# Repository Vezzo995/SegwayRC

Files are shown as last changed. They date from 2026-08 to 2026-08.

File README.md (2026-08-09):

# SegwayRC

Firmware for **SegwayRC**, a two-wheel self-balancing RC robot.
Arduino Nano · MPU-6050 · 2× NEMA 17 driven by TB6600 drivers.

📦 **3D model, bill of materials and assembly instructions:** [SegwayRC on MakerWorld](https://makerworld.com/en/models/3152173-segwayrc-arduino-nano-self-balancing-rc-robot#profileId-3560848)



---

## What it does

Balances on two wheels, drives forward and backward, and spins 360° on the spot, controlled from a standard 2.4 GHz RC transmitter. The angle estimate comes from an MPU-6050 through a complementary filter; a PID controller converts the tilt error into a step frequency for the two steppers.

## Requirements

Arduino IDE, and nothing else — **no external libraries needed**. The sketch only uses `Wire.h` and `util/atomic.h`, both bundled with the IDE.

Keep the `SegwayRC_v1.ino` file inside a folder named `SegwayRC_v1`: the Arduino IDE requires the sketch and its folder to share the same name.

## Pinout

| Pin | Function |
|---|---|
| D2 | PUL — left driver |
| D3 | DIR — left driver |
| D4 | PUL — right driver |
| D5 | DIR — right driver |
| D7 | RC Ch3 — arm / disarm |
| D8 | RC Ch1 — throttle |
| D9 | RC Ch2 — steering |
| A4 / SDA | MPU-6050 SDA |
| A5 / SCL | MPU-6050 SCL |
| D13 | Status LED |

RC inputs are read directly with pin-change interrupts (`PCINT0` and `PCINT2` groups), not with a library.

## Configuration

Everything tunable sits in the `#define` block at the top of the sketch.

| Constant | Default | Meaning |
|---|---|---|
| `MICROPASSI` | 8 | **Must match the TB6600 dip-switches** |
| `PASSI_GIRO` | 200 | Motor steps per revolution (1.8°) |
| `DIAM_RUOTA_M` | 0.105 | Wheel diameter, metres |
| `FREQ_MAX_HZ` | 12500 | Max step frequency per motor |
| `DT_S` | 0.002 | Loop period — 500 Hz |
| `Equilibrio` | −5.0 | Accelerometer mounting offset, degrees |
| `Kp` / `Ki` / `Kd` | 21 / 1 / 0.01 | PID gains |
| `K_RETRO_VELOCITA` | 0.015 | Speed feedback into the angle error |
| `ANGOLO_CADUTA` | 30 | Tilt angle at which the motors cut out |

The IMU runs at ±500 dps and ±4 g, with the DLPF set to roughly 43 Hz.

## First run

1. Set both TB6600 dip-switches to **1/8 microstepping and ~2 A**. If you change the microstepping, change `MICROPASSI` to match — otherwise the relationship between PID output and real speed is wrong and the gains no longer apply.
2. Flash the sketch with the **robot lifted off the ground and the wheels free**.
3. Power up with the robot lying flat and completely still: the gyro offsets are measured during startup.
4. Stand it upright, arm it with Ch3, and let go.

## Tuning

Start with `Kd` at zero. Raise `Kp` until the robot oscillates around vertical, then back it off about 20%. Add `Kd` until the oscillation damps out. Add `Ki` last and keep it small — too much integral makes the robot drift away instead of holding position.

If the robot balances but creeps steadily forward or backward, that's `Equilibrio`, not the gains: it's the mounting angle of the accelerometer, in degrees.

Serial debug output runs at 115200 baud and prints angle, setpoint, PID output and left step frequency every 200 ms. It is rate-limited and non-blocking on purpose — printing on every cycle saturates the transmit buffer and stalls the control loop.

## Known limitations

**The steppers run open loop.** The controller has no way of knowing whether the motors actually executed the steps it commanded. Under hard braking from high speed the motors can lose steps, the position estimate drifts away from reality, and the robot falls. It balances and drives well at moderate speed; it is not a racer.

A closed-loop version with encoder-equipped DC motors is in the works, and will fix exactly this.

**MPU-6050 DLPF latency.** The current filter setting introduces roughly 4.8 ms of delay — more than a full control loop period. Lowering it would improve phase margin at the cost of noise; it's on the list.

## Credits

The balancing algorithm derives from **[Joop Brokking's YABR project](http://www.brokking.net/yabr_main.html)**, adapted and largely rewritten for this hardware. The step generator, the RC failsafe, the acceleration ramp and the non-blocking serial output are new. Thanks to Joop for making his work public.

## Licence

Released under **[CC BY-NC-SA 4.0](https://creativecommons.org/licenses/by-nc-sa/4.0/)** — same as the 3D model. You may share and adapt it, with attribution, for non-commercial purposes, provided derivatives keep the same licence.

*Note: Creative Commons licences aren't designed for software. This one is chosen for consistency with the 3D model rather than for legal precision.*

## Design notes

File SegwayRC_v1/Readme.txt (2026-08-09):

Version 1.0

1) Added the Kalman filter to increase the speed:

Dati che mi servono (e come li ricavi in pratica)

m: 1,600 kg
massa totale del “corpo” sopra alle ruote (kg) – escludi la massa delle ruote se misuri separatamente I_w.

l: 0,08 m
distanza del baricentro dall’asse ruote (m) (verticale quando in equilibrio).

I_b: 0,0106112 kg·m²
momento d’inerzia del corpo attorno all’asse ruote (kg·m²). Se non lo sai, possiamo stimarlo:
– misura m e l, usa I_b ≈ m·l²·k con k tra 0.7 e 1.2 (dipende da come è distribuita la massa).

r: 0,0525 m
raggio ruota (m) = (diametro/2).

I_w: 0,0000826875 kg·m²
inerzia di ciascuna ruota+mozzo (kg·m²). Se non nota, stimiamo da massa ruota m_w=30gr e r=52,5mm (I_w ≈ ½ m_w r²).

N: 1
rapporto di riduzione (se c’è). Se direct drive, N=1.

K_t: costante di coppia motore (N·m/A).

K_e: costante di forza controelettromotrice (V·s/rad). Spesso K_t ≈ K_e in unità coerenti.

R_m: resistenza elettrica vista dal motore (Ω), includi driver se noto.

V_bat: tensione batteria (V).

bφ: attrito viscoso equivalente sul corpo (N·m·s/rad), se ignoto possiamo iniziare da 0.

bw: attrito viscoso vista ruota (N·m·s/rad), inizialmente 0.

ticks_per_rev: impulsi encoder per giro ruota (dopo riduzione).

dt: periodo di campionamento (s), tipico 0.005–0.01 (200–100 Hz).

σgyro, σacc, σenc: deviazioni standard rumore dei sensori (rad/s, rad, m o rad). Le stimiamo dai tuoi log (vedi sotto).

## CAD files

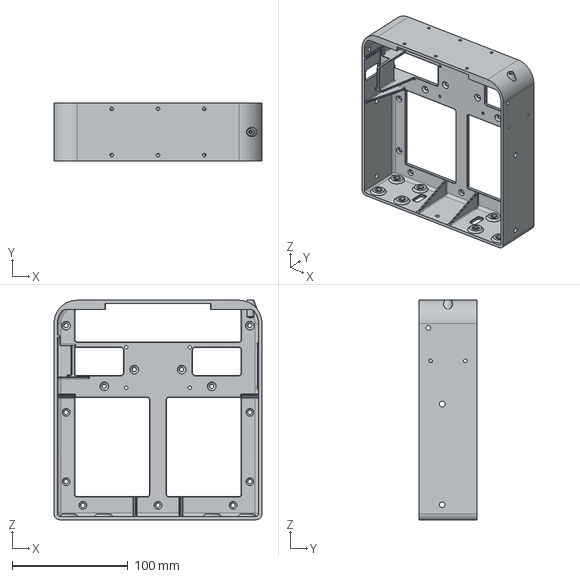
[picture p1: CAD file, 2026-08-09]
3D printing/kit - full 3D printed/SEG-P-012-01.stp
180.0 x 50.0 x 190.0 mm

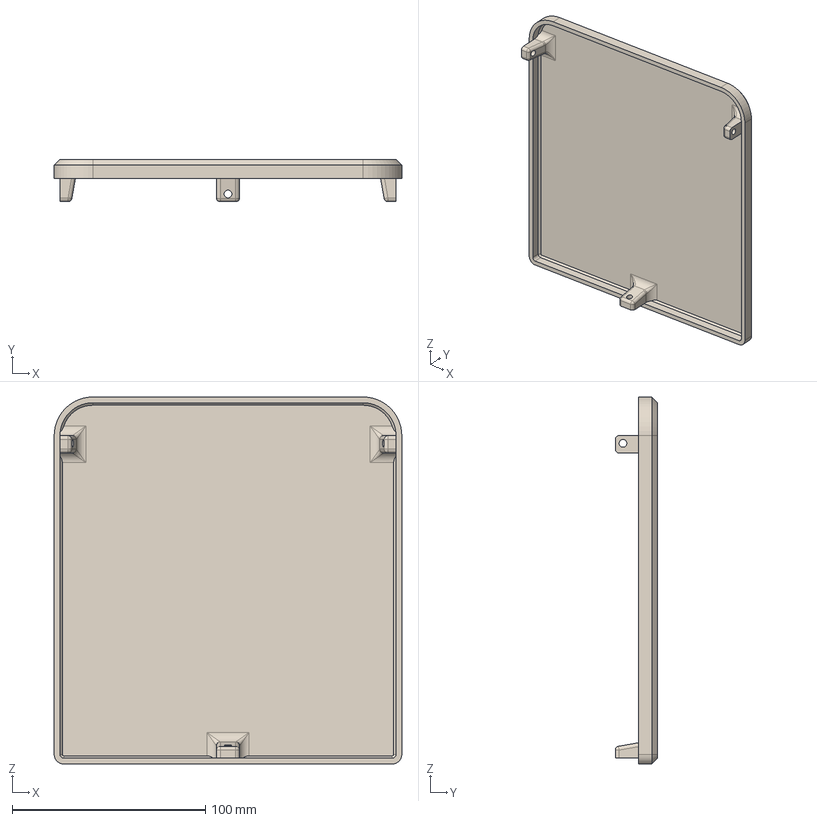
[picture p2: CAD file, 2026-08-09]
3D printing/kit - full 3D printed/SEG-P-023-00.stp
180.0 x 22.0 x 190.0 mm

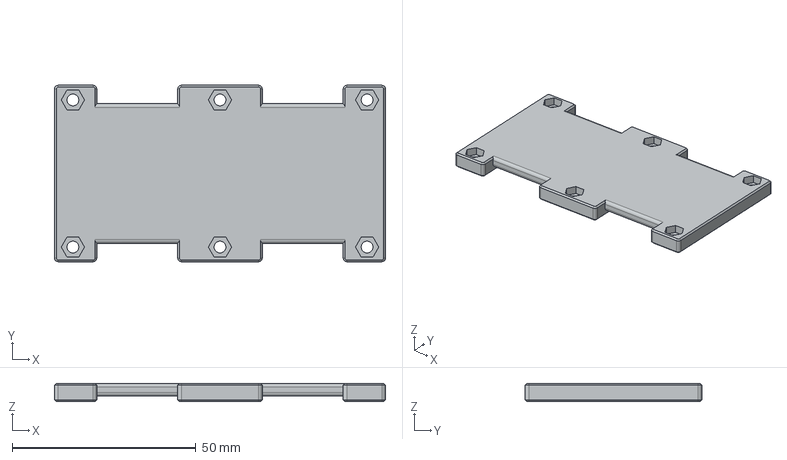
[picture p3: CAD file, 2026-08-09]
3D printing/Kit - Wood + 3D printed parts/SEG-P-017-00.stp
90.0 x 48.0 x 5.00 mm

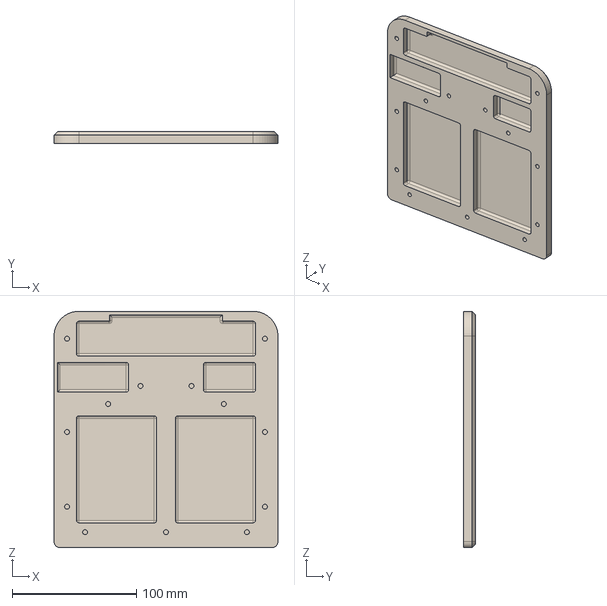
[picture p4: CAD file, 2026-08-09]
3D printing/kit - full 3D printed/SEG-P-022-00.stp
180.0 x 10.0 x 190.0 mm

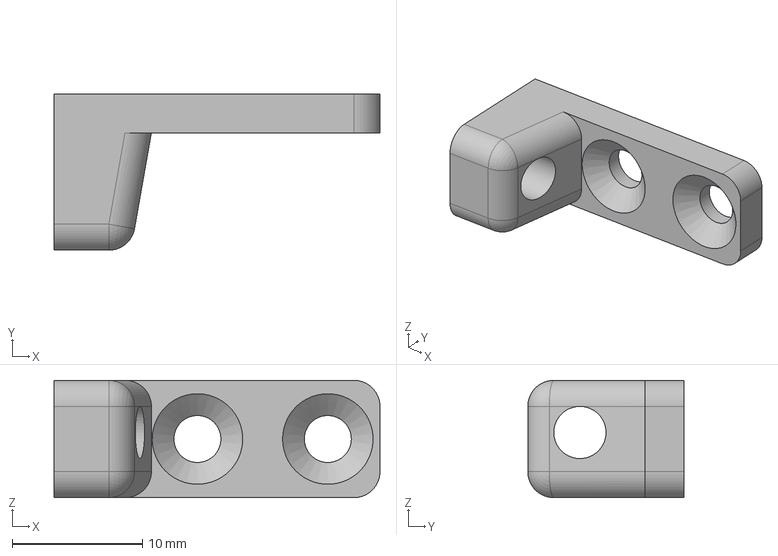
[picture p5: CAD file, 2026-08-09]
3D printing/Kit - Wood + 3D printed parts/SEG-P-024-00.stp
25.0 x 12.0 x 9.00 mm

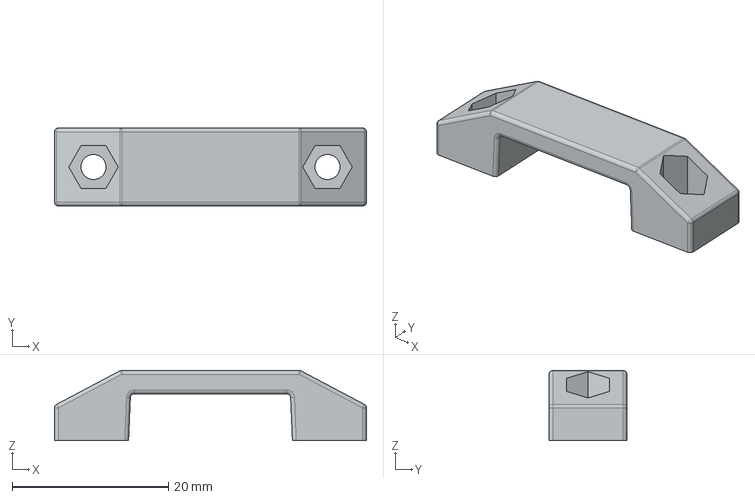
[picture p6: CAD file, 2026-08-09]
3D printing/Kit - Wood + 3D printed parts/SEG-P-014-00.stp
40.0 x 10.0 x 9.00 mm

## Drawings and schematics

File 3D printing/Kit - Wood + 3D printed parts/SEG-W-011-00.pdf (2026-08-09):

A

1 | 2 | 3 | 4 | 5 | 6 | 7 | 8 | 9 | 10 | 11 | 12 | 13

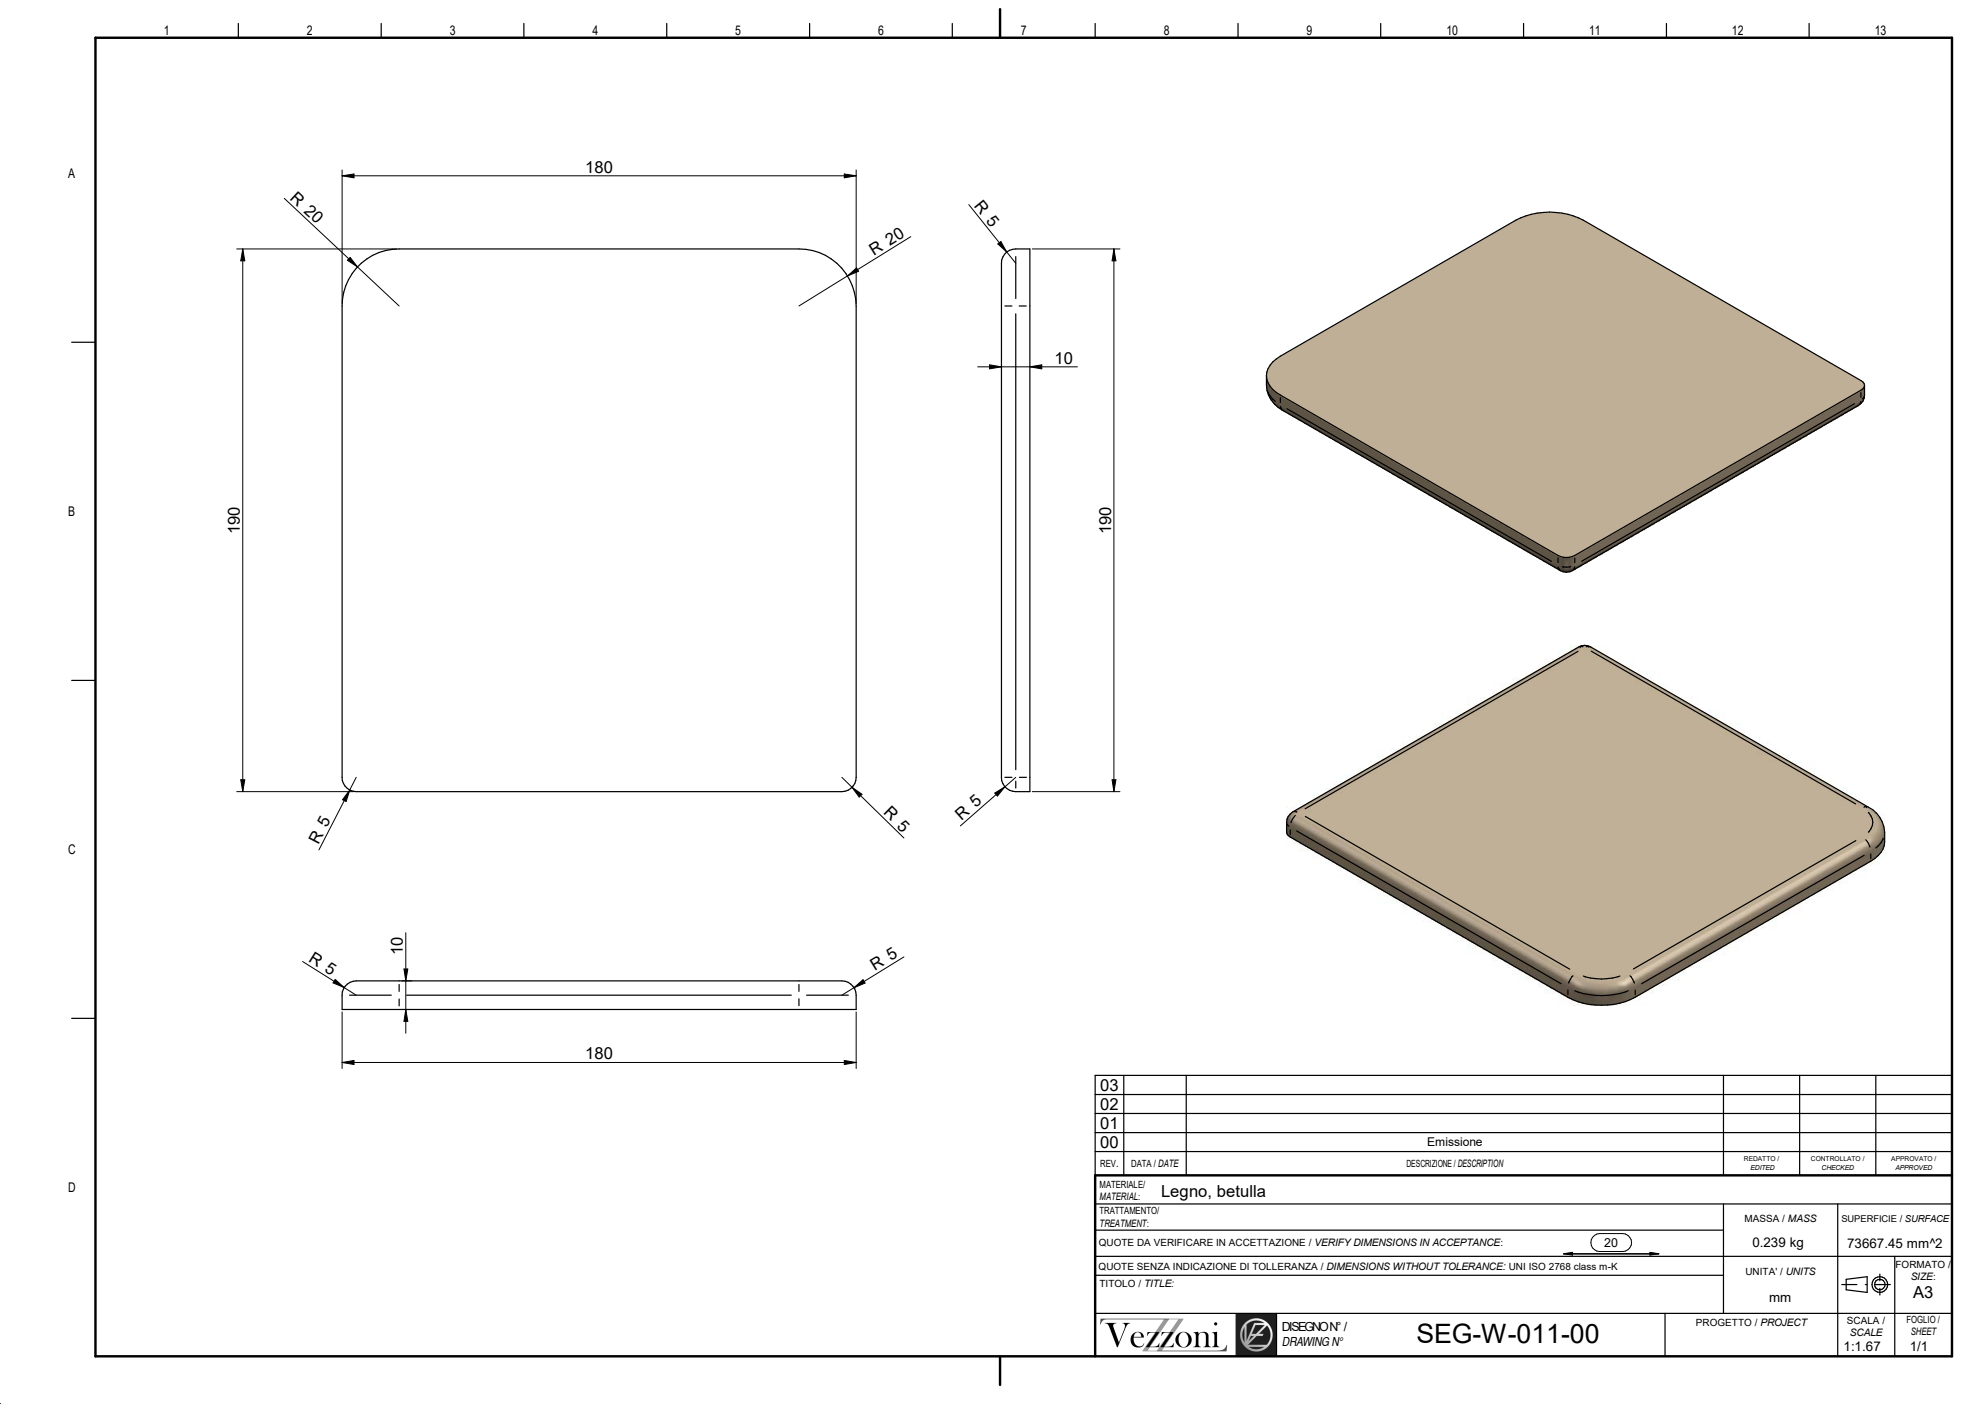
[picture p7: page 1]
SCALA / SCALE; FOGLIO / DISEGNO N° /; SHEET; DRAWING N°; MASSA / MASS; Legno, betulla; QUOTE DA VERIFICARE IN ACCETTAZIONE / VERIFY DIMENSIONS IN ACCEPTANCE:; TRATTAMENTO/ TREATMENT:; MATERIALE/ MATERIAL:; FORMATO / SIZE: A3; SUPERFICIE / SURFACE; PROGETTO / PROJECT; UNITA' / UNITS; SEG-W-011-00

03
02
01
00 | | Emissione

REV. | DATA / DATE | DESCRIZIONE / DESCRIPTION | REDATTO / EDITED | CONTROLLATO / CHECKED | APPROVATO / APPROVED

QUOTE SENZA INDICAZIONE DI TOLLERANZA / DIMENSIONS WITHOUT TOLERANCE: UNI ISO 2768 class m-K
TITOLO / TITLE:

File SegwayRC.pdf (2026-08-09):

1

2

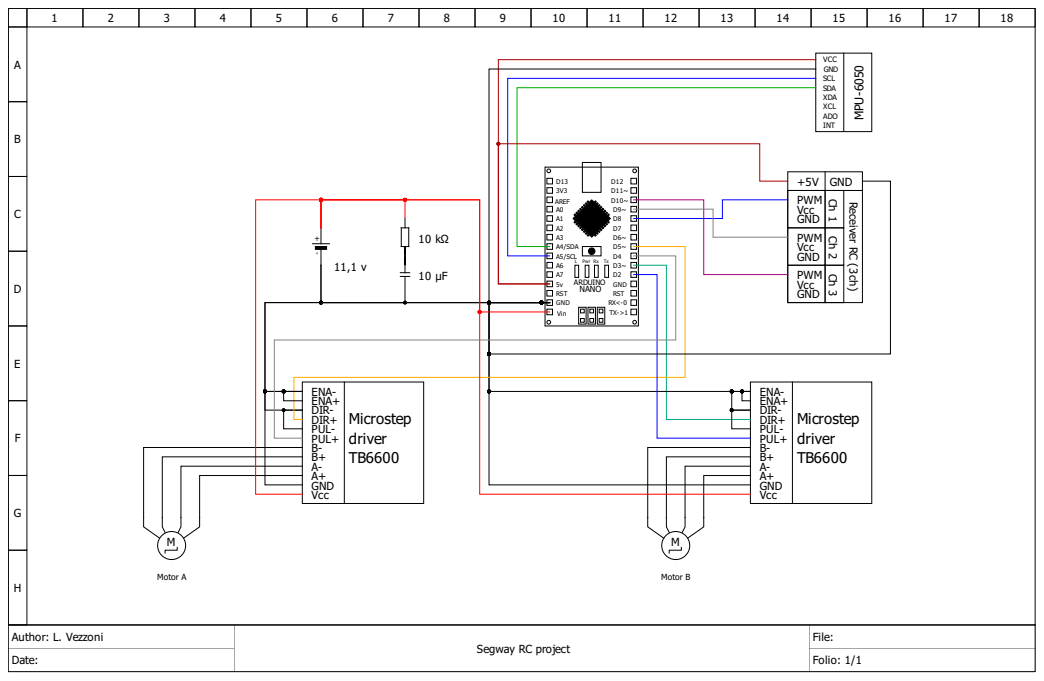
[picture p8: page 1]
ABCDEFGHAu; File: Date:; Folio: 1; 1MPU⁻⁶⁰⁵⁰; DA VCC XCL ADO SCL GND XDA INT - +; 11,1 v Vcc A- GND A+; Microstep driver TB6600 ENA- ENA+ DIR- DIR+ PUL- PUL+ B- B+; D3~ RST A6A0D13; Pwr; D2 D11~ RX<-0 3V3 RST; TX->1 D8 AREF; GND GND 5vVin A4/SDA; D7 A5/SCL; D4 ARDUINO NANO Tx; Mic; riv; R- DIR+ PUL- PUL+ B- B+; Receiver RC (3ch)

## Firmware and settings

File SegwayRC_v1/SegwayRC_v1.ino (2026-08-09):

// =============================================================================
//  SegwayRC v3.2  -  L. Vezzoni
//  Arduino Nano (ATmega328P @ 16 MHz) - MPU-6050 - 2x TB6600 - 2x NEMA17
//
// SegwayRC v1 firmware — L. Vezzoni
// Licensed under CC BY-NC-SA 4.0, same as the 3D model.
// Balancing algorithm derived from Joop Brokking's YABR project.
//
//  NOVITA' RISPETTO ALLA v3.1
//  --------------------------
//  1) Generatore di passi DDS (accumulatore di fase) al posto del divisore
//     intero: la frequenza e' regolabile con risoluzione di 0,76 Hz invece
//     che a scalini del 20% alle alte velocita'. Tetto alzato da ~12,4 kHz
//     a 25 kHz per motore.
//  2) BUG FISSATO: il fondo scala del giroscopio era impostato a +/-250 dps
//     ma il fattore di integrazione (0,000031) corrispondeva a +/-500 dps.
//     L'angolo integrato correva al doppio della velocita' reale. Ora il
//     registro e' su +/-500 dps, coerente col fattore (e con piu' margine
//     prima della saturazione durante una caduta veloce).
//  3) BUG FISSATO: PCICR abilitava solo il gruppo PCIE0 (pin 8,9) ma PCMSK2
//     era programmato per il pin 7. Il canale 1 (mode) veniva campionato
//     solo per caso. Ora e' abilitato anche PCIE2.
//  4) BUG FISSATO: "Beccheggio_gyro -= Calibrazione_imbardata" corrompeva il
//     valore di beccheggio con l'offset dell'imbardata. Rimosso.
//  5) La print() seriale su ogni ciclo mandava ~25 byte ogni 2 ms = 2,2 ms di
//     trasmissione a 115200. Saturava il buffer e BLOCCAVA il loop, rompendo
//     il tempo di ciclo. Ora e' limitata e non bloccante.
//  6) Rimosso il codice morto nella gestione del throttle (i due if con
//     +/-0,005 si annullavano a vicenda e il setpoint veniva comunque
//     riscritto al ciclo successivo).
//  7) Aggiunto failsafe radiocomando (se il ricevitore tace -> stick a zero).
//  8) Aggiunta rampa di accelerazione per non perdere passi.
//  9) Tutti i numeri magici sono ora #define commentati in cima.
//
//  ATTENZIONE ALLA TARATURA
//  ------------------------
//  Se MICROPASSI o FREQ_MAX_HZ cambiano, la relazione fra uscita del PID e
//  velocita' reale cambia: RITARA Kp/Ki/Kd partendo piu' bassi.
//  Prima accensione: robot SOLLEVATO da terra, ruote libere.
// =============================================================================

#include <Wire.h>
#include <util/atomic.h>

// ---------------------------------------------------------------- MECCANICA -
#define MICROPASSI          8        // <<< DEVE corrispondere ai DIP dei TB6600
#define PASSI_GIRO          200      // passi/giro del motore (1,8 gradi)
#define DIAM_RUOTA_M        0.105f   // diametro ruota in metri

// Frequenza di passo massima per motore [Hz]. Vincoli:
//   a) l'ISR gira a 50 kHz e puo' emettere al massimo 1 impulso ogni 2 tick
//      -> tetto assoluto 25000 Hz
//   b) i TB6600 hanno ingressi optoisolati: sopra ~20 kHz iniziano a perdere
//      impulsi. Con driver digitali (DM542) puoi salire.
//   c) se il motore stalla o "canta" senza girare, sei oltre la sua coppia:
//      abbassa questo valore oppure alza la tensione di alimentazione.
// Con 12500 Hz e 1/8 di passo -> 2,56 m/s teorici (9,2 km/h).
#define FREQ_MAX_HZ         12500.0f

// -------------------------------------------------------------- REGOLATORE --
float Equilibrio   = -5.0f;   // [gradi] offset di montaggio dell'accelerometro
float Kp           = 21.0f;   // guadagno proporzionale
float Ki           = 1.0f;    // guadagno integrale
float Kd           = 0.01f;   // guadagno derivativo

#define PID_MAX             600.0f   // saturazione uscita PID
#define PID_I_MAX           600.0f   // saturazione termine integrale (anti-windup)
#define BANDA_MORTA_PID     8.0f     // sotto questo valore i motori si fermano
#define ANGOLO_CADUTA       30.0f    // [gradi] oltre i quali il robot si arrende

// Retroazione di velocita': somma l'uscita del PID all'errore d'angolo.
// E' quello che fa "assestare" il robot a una velocita' costante invece di
// accelerare all'infinito. Piu' basso = il robot accelera di piu' per lo
// stesso angolo di inclinazione, ma diventa oscillatorio. Non scendere
// sotto ~0,008 senza ritarare.
#define K_RETRO_VELOCITA    0.015f

#define ANGOLO_MAX_COMANDO  5.0f    // [gradi] inclinazione max chiesta dallo stick
#define GUADAGNO_STERZO     1.0f     // moltiplica il differenziale di sterzo
#define BANDA_MORTA_RC      5        // zona morta stick (su scala -100..+100)

// Limite di variazione della frequenza di passo per ciclo (2 ms).
// Serve a non perdere passi: un passo-passo non puo' saltare istantaneamente
// da 0 a 12 kHz. Troppo basso = il robot non riesce a raddrizzarsi e cade.
// 1500 Hz/ciclo = 750 kHz/s, molto permissivo. Abbassa solo se perdi passi.
#define RAMPA_MAX_HZ_CICLO  1500.0f

// ------------------------------------------------------------------ SENSORE -
#define MPU_INDIRIZZO       0x68
#define DT_S                0.002f   // periodo di ciclo [s] = 500 Hz
#define GYRO_LSB_PER_DPS    65.5f    // fondo scala +/-500 dps
#define ACC_LSB_1G          8192.0f  // fondo scala +/-4 g
const float FATT_GYRO = DT_S / GYRO_LSB_PER_DPS;   // ~0,00003053

#define COMPL_A             0.9990f  // peso del giroscopio nel filtro complementare
#define COMPL_B             0.0010f  // peso dell'accelerometro (A + B = 1)

// ---------------------------------------------------------------- DEBUG/RC ---
#define DEBUG_SERIALE       1        // 0 per disattivarlo del tutto
#define DEBUG_OGNI_N_CICLI  100      // 100 cicli x 2 ms = stampa ogni 200 ms
#define RC_TIMEOUT_US       500000UL // 0,5 s senza impulsi -> failsafe

// ------------------------------------------------------------- MASCHERE PIN --
// D2 = PUL sinistro, D3 = DIR sinistro, D4 = PUL destro, D5 = DIR destro
#define M_PUL_SX  0b00000100
#define M_DIR_SX  0b00001000
#define M_PUL_DX  0b00010000
#define M_DIR_DX  0b00100000
#define LED_PIN   13

// =============================================================================
//  VARIABILI
// =============================================================================

// Condivise con l'ISR del generatore di passi (accesso atomico obbligatorio)
volatile uint16_t inc_sx = 0, inc_dx = 0;   // incrementi DDS
volatile uint8_t  dir_sx = 0, dir_dx = 0;   // 0 = avanti, 1 = indietro

// Condivise con l'ISR del radiocomando
volatile unsigned long timer_rc[4];
volatile byte  ultimo_canale[3];
volatile int   input_rc[3];
volatile unsigned long ultimo_impulso_rc = 0;

// Regolatore
float PID_errore, PID_i_mem, PID_setpoint, Uscita_PID, PID_ultimo_errore;
float PID_uscita_sx, PID_uscita_dx;
float PID_setpoint_bilanciamento;
float Angolo_gyro, Angolo_acc;
float freq_sx_prec = 0, freq_dx_prec = 0;

// Sensore
int  Beccheggio_gyro, Imbardata_gyro, Accelerometro_z;
long Calibrazione_imbardata, Calibrazione_beccheggio;

// Servizio
byte Avvio = 0;
int  throttle, steering, mode;
unsigned long Tempo_ciclo;
uint16_t contatore_debug = 0;

// =============================================================================
//  SETUP
// =============================================================================
void setup(){
  Serial.begin(115200);
  Wire.begin();
  TWBR = 12;                     // I2C a 400 kHz

  pinMode(2, OUTPUT); pinMode(3, OUTPUT);
  pinMode(4, OUTPUT); pinMode(5, OUTPUT);
  pinMode(LED_PIN, OUTPUT);
  PORTD &= ~(M_PUL_SX | M_PUL_DX);

  // --- Timer2: interrupt ogni 20 us (50 kHz) per il generatore di passi ---
  TCCR2A = 0;
  TCCR2B = 0;
  TIMSK2 |= (1 << OCIE2A);
  TCCR2B |= (1 << CS21);         // prescaler 8 -> 2 MHz
  OCR2A   = 39;                  // 40 conteggi = 20 us
  TCCR2A |= (1 << WGM21);        // modalita' CTC

  // --- MPU-6050 ---
  scriviMPU(0x6B, 0x00);   // PWR_MGMT_1: sveglia il sensore
  scriviMPU(0x1B, 0x08);   // GYRO_CONFIG: +/-500 dps  <-- CORRETTO (era 0x00)
  scriviMPU(0x1C, 0x08);   // ACCEL_CONFIG: +/-4 g
  scriviMPU(0x1A, 0x03);   // CONFIG: DLPF ~43 Hz
                           // (prova 0x02 = 94 Hz se vuoi meno ritardo di fase,
                           //  a costo di piu' rumore)

  // --- Interrupt radiocomando ---
  // v3.1 abilitava solo PCIE0: il pin 7 (PCINT23, gruppo 2) non generava mai
  // interrupt. Ora entrambi i gruppi sono attivi.
  PCICR  |= (1 << PCIE0) | (1 << PCIE2);
  PCMSK0 |= (1 << PCINT0);   // D8  - throttle
  PCMSK0 |= (1 << PCINT1);   // D9  - steering
  PCMSK2 |= (1 << PCINT23);  // D7  - mode

  // --- Calibrazione offset giroscopio (il robot deve stare FERMO) ---
  for(int i = 0; i < 800; i++){
    if(i % 100 == 0) digitalWrite(LED_PIN, !digitalRead(LED_PIN));
    Wire.beginTransmission(MPU_INDIRIZZO);
    Wire.write(0x43);
    Wire.endTransmission();
    Wire.requestFrom(MPU_INDIRIZZO, 4);
    Calibrazione_imbardata  += Wire.read() << 8 | Wire.read();
    Calibrazione_beccheggio += Wire.read() << 8 | Wire.read();
    delayMicroseconds(1700);
  }
  Calibrazione_imbardata  /= 800;
  Calibrazione_beccheggio /= 800;
  digitalWrite(LED_PIN, LOW);

#if DEBUG_SERIALE
  Serial.println(F("\nSegwayRC v3.2"));
  Serial.print(F("Micropassi 1/"));   Serial.println(MICROPASSI);
  Serial.print(F("Freq max Hz "));    Serial.println(FREQ_MAX_HZ);
  Serial.print(F("Vel max m/s "));
  Serial.println(FREQ_MAX_HZ / (PASSI_GIRO * MICROPASSI) * 3.14159f * DIAM_RUOTA_M);
#endif

  Tempo_ciclo = micros() + (unsigned long)(DT_S * 1000000.0f);
}

// =============================================================================
//  LOOP PRINCIPALE  (500 Hz)
// =============================================================================
void loop(){

  // ---------------------------------------------------- lettura radiocomando -
  int rc[3];
  unsigned long t_rc;
  ATOMIC_BLOCK(ATOMIC_RESTORESTATE){       // gli int sono a 16 bit: lettura
    rc[0] = input_rc[0];                   // non atomica -> valori corrotti
    rc[1] = input_rc[1];
    rc[2] = input_rc[2];
    t_rc  = ultimo_impulso_rc;
  }

  if((micros() - t_rc) > RC_TIMEOUT_US){   // FAILSAFE: ricevitore muto
    throttle = 0;
    steering = 0;
    mode     = 0;
  } else {
    mode     = rc[0];
    throttle = map(constrain(rc[1], 1000, 2000), 1000, 2000, -100, 100);
    steering = map(constrain(rc[2], 1000, 2000), 1000, 2000, -100, 100);
  }

  // -------------------------------------------------------- stima dell'angolo -
  // Accelerometro: da' l'angolo assoluto ma e' rumoroso e sensibile alle
  // accelerazioni del veicolo.
  Wire.beginTransmission(MPU_INDIRIZZO);
  Wire.write(0x3F);                        // ACCEL_ZOUT_H
  Wire.endTransmission();
  Wire.requestFrom(MPU_INDIRIZZO, 2);
  Accelerometro_z = Wire.read() << 8 | Wire.read();
  Accelerometro_z = constrain(Accelerometro_z, -(int)ACC_LSB_1G, (int)ACC_LSB_1G);
  Angolo_acc = asin((float)Accelerometro_z / ACC_LSB_1G) * 57.296f - Equilibrio;

  // Avvio automatico quando il robot viene messo in verticale
  if(Avvio == 0 && Angolo_acc > -0.5f && Angolo_acc < 0.5f){
    Angolo_gyro = Angolo_acc;
    Avvio = 1;
  }

  // Giroscopio: preciso nel breve periodo ma deriva. Si integra.
  Wire.beginTransmission(MPU_INDIRIZZO);
  Wire.write(0x43);                        // GYRO_XOUT_H
  Wire.endTransmission();
  Wire.requestFrom(MPU_INDIRIZZO, 4);
  Imbardata_gyro  = Wire.read() << 8 | Wire.read();
  Beccheggio_gyro = Wire.read() << 8 | Wire.read();
  Beccheggio_gyro -= Calibrazione_beccheggio;
  Angolo_gyro += Beccheggio_gyro * FATT_GYRO;

  // Filtro complementare: il giroscopio domina, l'accelerometro corregge
  // lentamente la deriva. Costante di tempo = DT * A / B = 2 s.
  Angolo_gyro = Angolo_gyro * COMPL_A + Angolo_acc * COMPL_B;

  // ------------------------------------------------------------------- PID --
  PID_errore = Angolo_gyro - PID_setpoint_bilanciamento - PID_setpoint;

  // Retroazione di velocita': "conta" anche quanto stanno gia' correndo le
  // ruote, cosi' il robot si stabilizza a velocita' costante.
  if(Uscita_PID > 10.0f || Uscita_PID < -10.0f)
    PID_errore += Uscita_PID * K_RETRO_VELOCITA;

  PID_i_mem += Ki * PID_errore;
  PID_i_mem  = constrain(PID_i_mem, -PID_I_MAX, PID_I_MAX);

  Uscita_PID = Kp * PID_errore + PID_i_mem + Kd * (PID_errore - PID_ultimo_errore);
  Uscita_PID = constrain(Uscita_PID, -PID_MAX, PID_MAX);
  PID_ultimo_errore = PID_errore;

  if(Uscita_PID < BANDA_MORTA_PID && Uscita_PID > -BANDA_MORTA_PID)
    Uscita_PID = 0;

  // Caduta o non ancora avviato -> tutto a zero
  if(Angolo_gyro > ANGOLO_CADUTA || Angolo_gyro < -ANGOLO_CADUTA || Avvio == 0){
    Uscita_PID = 0;
    PID_i_mem  = 0;
    Avvio      = 0;
    PID_setpoint_bilanciamento = 0;
  }

  // --------------------------------------------------- comandi di movimento --
  PID_uscita_sx = Uscita_PID;
  PID_uscita_dx = Uscita_PID;

  // Sterzo: differenziale fra le due ruote
  if(steering > BANDA_MORTA_RC || steering < -BANDA_MORTA_RC){
    PID_uscita_sx += steering * GUADAGNO_STERZO;
    PID_uscita_dx -= steering * GUADAGNO_STERZO;
  }

  // Avanti/indietro: lo stick chiede un ANGOLO di inclinazione, non una
  // velocita'. E' il modo giusto: un segway accelera solo se si inclina.
  if(throttle > BANDA_MORTA_RC || throttle < -BANDA_MORTA_RC){
    PID_setpoint = ANGOLO_MAX_COMANDO * throttle / 100.0f;
  } else {
    // Rientro morbido a zero quando si rilascia lo stick
    if(PID_setpoint > 0.1f)       PID_setpoint -= 0.05f;
    else if(PID_setpoint < -0.1f) PID_setpoint += 0.05f;
    else                          PID_setpoint  = 0.0f;
  }

  // Auto-ricerca del punto di equilibrio: se da fermo il robot deve comunque
  // spingere per stare su, significa che il baricentro non e' sopra l'asse.
  if(PID_setpoint == 0.0f){
    if(Uscita_PID < 0) PID_setpoint_bilanciamento += 0.0015f;
    if(Uscita_PID > 0) PID_setpoint_bilanciamento -= 0.0015f;
  }

  // ------------------------------------------- conversione in passi/secondo --
  float f_sx = frequenzaDaPID(PID_uscita_sx);
  float f_dx = frequenzaDaPID(PID_uscita_dx);

  f_sx = limitaRampa(f_sx, freq_sx_prec);  freq_sx_prec = f_sx;
  f_dx = limitaRampa(f_dx, freq_dx_prec);  freq_dx_prec = f_dx;

  // DDS: incremento = freq / 50000 * 65536
  uint16_t i_sx = (uint16_t)(fabs(f_sx) * 1.31072f);
  uint16_t i_dx = (uint16_t)(fabs(f_dx) * 1.31072f);
  uint8_t  d_sx = (f_sx < 0) ? 1 : 0;
  uint8_t  d_dx = (f_dx < 0) ? 1 : 0;

  ATOMIC_BLOCK(ATOMIC_RESTORESTATE){
    inc_sx = i_sx;  dir_sx = d_sx;
    inc_dx = i_dx;  dir_dx = d_dx;
  }

  // ----------------------------------------------------------------- debug ---
#if DEBUG_SERIALE
  if(++contatore_debug >= DEBUG_OGNI_N_CICLI){
    contatore_debug = 0;
    // Non bloccante: stampa solo se c'e' spazio nel buffer di trasmissione
    if(Serial.availableForWrite() > 40){
      Serial.print(Angolo_gyro, 1); Serial.print(' ');
      Serial.print(PID_setpoint, 1); Serial.print(' ');
      Serial.print((int)Uscita_PID); Serial.print(' ');
      Serial.println((int)f_sx);
    }
  }
#endif

  // ------------------------------------------- tempo di ciclo fisso a 2 ms ---
  // Se questo while non attende mai, il loop e' in ritardo: la stima
  // dell'angolo diventa sbagliata perche' FATT_GYRO presuppone DT_S esatto.
  while(Tempo_ciclo > micros());
  Tempo_ciclo += (unsigned long)(DT_S * 1000000.0f);
}

// =============================================================================
//  FUNZIONI DI SUPPORTO
// =============================================================================

void scriviMPU(byte reg, byte val){
  Wire.beginTransmission(MPU_INDIRIZZO);
  Wire.write(reg);
  Wire.write(val);
  Wire.endTransmission();
}

// Mappa l'uscita del PID (+/-PID_MAX) sulla frequenza di passo (+/-FREQ_MAX_HZ).
// La curva iperbolica e' quella originale di YABR: compensa il fatto che la
// coppia di un passo-passo cala con la velocita', quindi serve piu' "comando"
// per ottenere l'ultimo tratto di giri. E' normalizzata perche' a PID_MAX
// restituisca esattamente FREQ_MAX_HZ.
// Metti MAPPA_LINEARE a 1 se preferisci una risposta lineare (piu' facile da
// modellare, ma dovrai rialzare Kp).
#define MAPPA_LINEARE 0

float frequenzaDaPID(float x){
  float a = fabs(x);
  if(a < 1.0f) return 0.0f;
  if(a > PID_MAX) a = PID_MAX;

  float f;
#if MAPPA_LINEARE
  f = FREQ_MAX_HZ * a / PID_MAX;
#else
  const float k_max = (PID_MAX + 9.0f) / (1091.0f - PID_MAX);
  float k = (a + 9.0f) / (1091.0f - a);
  f = FREQ_MAX_HZ * k / k_max;
#endif

  if(f > 25000.0f) f = 25000.0f;      // tetto fisico dell'ISR
  return (x < 0) ? -f : f;
}

// Limita la variazione di frequenza per ciclo: un motore passo-passo che
// riceve un salto di frequenza troppo grande perde il sincronismo e si ferma
// (e il robot cade). Questo e' il motivo per cui i passo-passo hanno bisogno
// di rampe mentre un motore CC no.
float limitaRampa(float richiesta, float precedente){
  float delta = richiesta - precedente;
  if(delta >  RAMPA_MAX_HZ_CICLO) return precedente + RAMPA_MAX_HZ_CICLO;
  if(delta < -RAMPA_MAX_HZ_CICLO) return precedente - RAMPA_MAX_HZ_CICLO;
  return richiesta;
}

// =============================================================================
//  ISR GENERATORE DI PASSI  (50 kHz)
// =============================================================================
//  Sintesi digitale diretta (DDS). Un accumulatore a 16 bit viene incrementato
//  a ogni tick; ogni volta che va in overflow si emette un impulso.
//    frequenza = incremento / 65536 * 50000 Hz
//  Risoluzione: 0,76 Hz su tutto il campo. Il metodo precedente (divisore
//  intero di tick) aveva scalini del 20% oltre i 10 kHz, cioe' il controllo
//  non riusciva piu' a dosare la velocita' proprio dove serviva.
// =============================================================================
ISR(TIMER2_COMPA_vect){
  static uint16_t acc_sx = 0, acc_dx = 0;
  static uint8_t  dir_sx_att = 255, dir_dx_att = 255;
  uint16_t prec;

  // Chiude gli impulsi aperti al tick precedente (larghezza 20 us, ampiamente
  // sopra il minimo richiesto dai TB6600)
  PORTD &= ~(M_PUL_SX | M_PUL_DX);

  // ---- motore sinistro ----
  if(dir_sx_att != dir_sx){
    dir_sx_att = dir_sx;
    if(dir_sx_att) PORTD &= ~M_DIR_SX; else PORTD |= M_DIR_SX;
    acc_sx = 0;              // salta un tick: garantisce >=20 us di setup
  } else {                   // fra il cambio di DIR e il fronte di PUL
    prec = acc_sx;
    acc_sx += inc_sx;
    if(acc_sx < prec) PORTD |= M_PUL_SX;
  }

  // ---- motore destro (DIR invertita: montaggio speculare) ----
  if(dir_dx_att != dir_dx){
    dir_dx_att = dir_dx;
    if(dir_dx_att) PORTD |= M_DIR_DX; else PORTD &= ~M_DIR_DX;
    acc_dx = 0;
  } else {
    prec = acc_dx;
    acc_dx += inc_dx;
    if(acc_dx < prec) PORTD |= M_PUL_DX;
  }
}

// =============================================================================
//  ISR RADIOCOMANDO
// =============================================================================
ISR(PCINT0_vect){
  unsigned long ora = micros();

  // Canale 1 - mode (D7, PIND bit 7)
  if(ultimo_canale[0] == 0 && (PIND & B10000000)){
    ultimo_canale[0] = 1;  timer_rc[1] = ora;
  } else if(ultimo_canale[0] == 1 && !(PIND & B10000000)){
    ultimo_canale[0] = 0;  input_rc[0] = ora - timer_rc[1];
    ultimo_impulso_rc = ora;
  }

  // Canale 2 - throttle (D8, PINB bit 0)
  if(ultimo_canale[1] == 0 && (PINB & B00000001)){
    ultimo_canale[1] = 1;  timer_rc[2] = ora;
  } else if(ultimo_canale[1] == 1 && !(PINB & B00000001)){
    ultimo_canale[1] = 0;  input_rc[1] = ora - timer_rc[2];
    ultimo_impulso_rc = ora;
  }

  // Canale 3 - steering (D9, PINB bit 1)
  if(ultimo_canale[2] == 0 && (PINB & B00000010)){
    ultimo_canale[2] = 1;  timer_rc[3] = ora;
  } else if(ultimo_canale[2] == 1 && !(PINB & B00000010)){
    ultimo_canale[2] = 0;  input_rc[2] = ora - timer_rc[3];
    ultimo_impulso_rc = ora;
  }
}

// Il pin 7 appartiene al gruppo PCINT2: stessa routine.
ISR(PCINT2_vect, ISR_ALIASOF(PCINT0_vect));
